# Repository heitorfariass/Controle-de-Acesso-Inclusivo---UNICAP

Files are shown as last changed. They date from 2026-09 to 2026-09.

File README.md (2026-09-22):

# ♿ Sistema Robótico de Destravamento com RFID — Acessibilidade UNICAP

<p align="center">
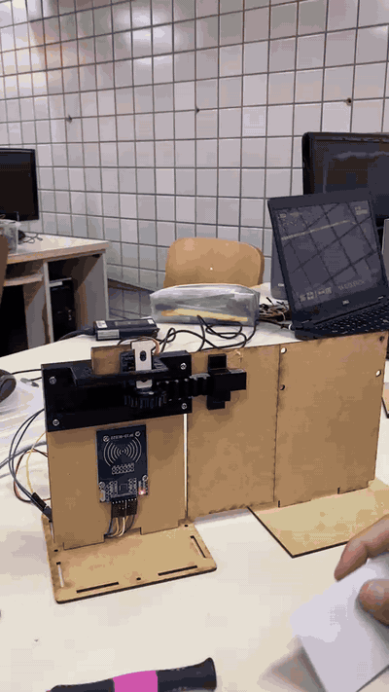
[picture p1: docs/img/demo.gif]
Sistema de destravamento RFID em funcionamento: o cartão é aproximado e a trava do portão é acionada pelo mecanismo impresso em 3D
  
</p>

> **Uma porta que abre sem pedir ajuda.** Projeto acadêmico da disciplina de Robótica Inclusiva (UNICAP) que devolve autonomia a estudantes com mobilidade reduzida: basta aproximar o cartão e a trava destrava sozinha.








➡️ **[Documentação técnica completa (PDF)](docs/documentacao-tecnica.pdf)** • **[Peças para impressão 3D](hardware/stl/)** • **[Vídeo completo do protótipo](docs/img/demo.mp4)**

---

## 🎯 O problema

Na universidade, o acesso de estudantes cadeirantes às instalações depende de que **alguém abra manualmente a porta de acessibilidade**. Na prática, isso significa esperar, chamar terceiros e, muitas vezes, passar por situações constrangedoras para realizar algo tão simples quanto entrar em uma sala.

## 💡 A solução

Um **sistema de destravamento com RFID** controlado por Arduino: ao aproximar um cartão autorizado, um servo motor aciona uma trava impressa em 3D e a porta se abre — sem depender de ninguém. O cadastro de novos usuários é feito pelo próprio dispositivo, com um **Cartão Mestre**, e tudo fica salvo na memória do Arduino, **100% offline**.

| Sem o projeto 😕 | Com o projeto 😃 |
| :--- | :--- |
| Esperar um terceiro abrir a porta | Aproximar o cartão e entrar |
| Dependência e constrangimento | Autonomia e independência |
| Nenhum registro de acesso | Base pronta para logs futuros |

---

## 🎬 Demonstração

> ⚡ O GIF do topo é gerado do vídeo real do protótipo — [assista ao vídeo completo, com áudio](docs/img/demo.mp4).

### 🛠️ Jornada de desenvolvimento

O projeto evoluiu por marcos claros — dos primeiros testes de leitura ao mecanismo funcional:

| 1️⃣ Primeiros testes do RFID | 2️⃣ Montagem mecânica v1 (MDF) |
| :---: | :---: |
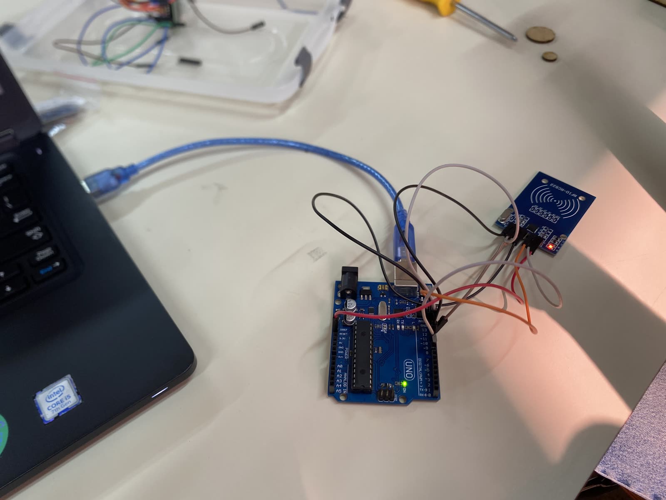
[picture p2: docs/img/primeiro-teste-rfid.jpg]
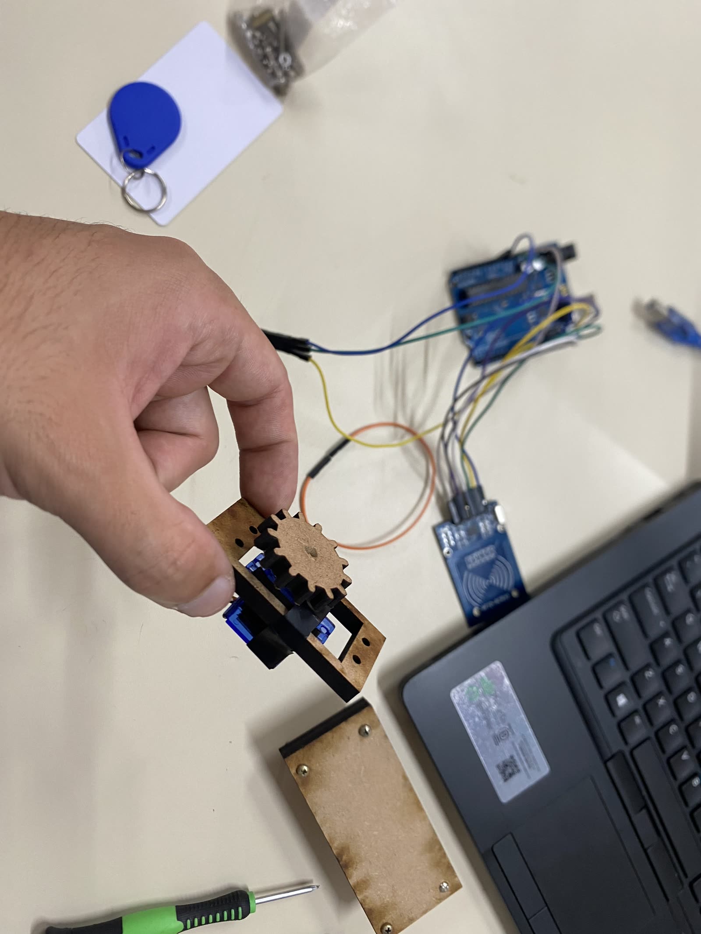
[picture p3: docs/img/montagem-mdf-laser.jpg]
|  |  |
| *Primeiro contato e leituras com o módulo RC522* | *Estrutura em MDF cortado a laser — substituída por peças impressas em 3D (ver [Desafios](#-desafios-e-soluções))* |

---

## ⚙️ Funcionalidades

- **🔓 Controle de acesso físico:** destravamento automatizado via leitura de tags RFID (13,56 MHz).
- **🔀 Acionamento em alternância (toggle):** a mesma leitura abre ou fecha a porta.
- **🗝️ Gestão via Master Card:** cadastro e remoção de usuários direto no dispositivo, sem plugar o Arduino no computador.
- **💾 Armazenamento não-volátil:** UIDs salvos na EEPROM nativa (até 10 cartões no código atual, expansível) — sobrevive a quedas de energia.
- **📴 100% offline:** sem internet, sem servidor, sem nuvem.

---

## 🧠 Arquitetura

O firmware é uma **máquina de estados** com três modos de operação, o que permite administrar usuários pelo próprio leitor:

```mermaid
stateDiagram-v2
    [*] --> NORMAL

    NORMAL --> ADMIN : Master Card
    NORMAL --> NORMAL : Tag autorizada → abre/fecha porta
    NORMAL --> NORMAL : Tag desconhecida → acesso negado

    ADMIN --> NORMAL : Master Card (encerra o modo)
    ADMIN --> NORMAL : Tag nova → cadastrada na EEPROM
    ADMIN --> AGUARDANDO_REMOCAO : Tag já cadastrada

    AGUARDANDO_REMOCAO --> NORMAL : Mesma tag → confirma remoção
    AGUARDANDO_REMOCAO --> NORMAL : Master Card → cancela
```

### Fluxo de sinais do sistema

```mermaid
flowchart LR
    A[Cartão RFID] -->|rádio 13,56 MHz| B[Leitor RC522]
    B -->|SPI| C[Arduino Uno<br/>máquina de estados + EEPROM]
    C -->|PWM| D[Servo 360°]
    D --> E[Mecanismo<br/>cremalheira e pinhão 3D]
    E --> F[Trava do portão]
    C <-.->|gravação/leitura| G[EEPROM<br/>até 10 UIDs]
```

---

## 🛠️ Hardware

### Lista de componentes (BOM)

| Componente | Especificação | Qtd. | Custo estimado* |
| :--- | :--- | :---: | :--- |
| Arduino Uno | R3 (ou compatível) | 1 | R$ 60–120 |
| Leitor RFID | RC522, 13,56 MHz | 1 | R$ 10–20 |
| Servo motor | SG90 modificado p/ rotação contínua (360°) | 1 | R$ 15–30 |
| Cartões/tags RFID | Kit com cartões e chaveiros | 1 kit | R$ 10–15 |
| Protoboard + jumpers | — | 1 kit | R$ 20–40 |
| Mecânica | MDF cortado a laser + peças impressas em 3D | 1 | R$ 30–60 |
| **Total** | | | **≈ R$ 150–300** |

> \* Valores aproximados em reais, com componentes nacionais/genéricos.

### 🔌 Esquema de ligação (pinagem)

| Componente | Pino do componente | Pino do Arduino |
| :--- | :--- | :--- |
| RFID RC522 | SDA (SS) | Digital 10 |
| RFID RC522 | SCK | Digital 13 |
| RFID RC522 | MOSI | Digital 11 |
| RFID RC522 | MISO | Digital 12 |
| RFID RC522 | IRQ | *Não conectado* |
| RFID RC522 | RST | Digital 9 |
| RFID RC522 | GND | GND |
| RFID RC522 | **3.3V** | 3.3V |
| Servo motor | Sinal (laranja/amarelo) | Digital 7 |
| Servo motor | VCC (vermelho) | 5V *(recomendado fonte externa)* |
| Servo motor | GND (marrom/preto) | GND |

> ⚠️ **Atenção:** o RC522 **não tolera 5V** no pino de alimentação — conecte-o **exclusivamente ao 3.3V**, sob risco de queimar o módulo.

---

## 🖨️ Mecânica

A trava é um mecanismo de **cremalheira e pinhão** impresso em 3D, acoplado ao servo de rotação contínua; a estrutura do portão é cortada a laser em MDF.

As **quatro peças** do mecanismo estão prontas para reimpressão em [`hardware/stl/`](hardware/stl/):

| Peça | Arquivo | Função |
| :--- | :--- | :--- |
| Pinhão (engrenagem) | [`gear.stl`](hardware/stl/gear.stl) | Acoplado ao servo, converte rotação em movimento linear |
| Cremalheira | [`gear_rack.stl`](hardware/stl/gear_rack.stl) | Trava linear acionada pelo pinhão |
| Suporte do motor | [`motor_holder.stl`](hardware/stl/motor_holder.stl) | Fixa o servo à estrutura |
| Suporte da cremalheira | [`rack_holder.stl`](hardware/stl/rack_holder.stl) | Guiamento e fixação da cremalheira |

- **Parâmetros de impressão:** material, infill e suportes documentados em [`hardware/stl/README.md`](hardware/stl/README.md)

---

## 🚀 Como instalar e usar

### 1. Dependências

Instale as bibliotecas no IDE do Arduino (Sketch → Incluir Biblioteca → Gerenciar Bibliotecas):

- [`MFRC522`](https://github.com/miguelbalboa/rfid) (GithubCommunity)
- `Servo` (nativa)
- `EEPROM` (nativa)
- `SPI` (nativa)

### 2. Configure o Cartão Mestre

Abra `firmware/destravamento_rfid/destravamento_rfid.ino` e informe o UID do cartão administrador na variável `masterID`:

```cpp
String masterID = "63:13:ED:1B";
```

> 💡 Para descobrir o UID de um cartão, rode um sketch de leitura RFID (ou o próprio firmware) e veja o UID no Monitor Serial (9600 baud).

### 3. Faça o upload

Conecte o Arduino Uno via USB, selecione a placa e a porta corretas e clique em **Upload**. Abra o **Monitor Serial (9600)** para acompanhar tudo em tempo real.

### 4. Modo de operação

**No dia a dia (Modo NORMAL):**
| Ação | Resultado |
| :--- | :--- |
| Aproximar cartão **cadastrado** | Porta destrava/trava (alternância) |
| Aproximar cartão **desconhecido** | Acesso negado |

**Administrando usuários:**
1. 🗝️ Aproxime o **Master Card** → o sistema entra em **MODO ADMIN**.
2. ➕ Aproxime uma **tag nova** → ela é cadastrada e salva na EEPROM, e o sistema volta ao modo normal.
3. ➖ Aproxime uma **tag já cadastrada** (em modo admin) → o sistema pede confirmação: aproxime **a mesma tag novamente** para removê-la, ou o **Master Card** para cancelar.
4. 🗝️ Aproxime o **Master Card** de novo → encerra o modo admin.

Tudo é confirmado no Monitor Serial — nenhuma ferramenta além do leitor é necessária.

---

## 🧗 Desafios e soluções

| Desafio | Como resolvemos |
| :--- | :--- |
| A estrutura em MDF cortado a laser não funcionou como esperado | Redesenho completo do mecanismo para **impressão 3D** (cremalheira, pinhão e suportes), com tolerâncias e resistência adequadas — [peças disponíveis no repo](hardware/stl/) |
| O RC522 queima com 5V | Alimentação dedicada ao 3.3V do Arduino e aviso documentado na pinagem |
| Servo de rotação contínua não tem posição fixa | Calibração do neutro em 90° e pulsos de 80°/100° com temporização de 1 s para abrir/fechar de forma controlada |
| Cadastro não poderia depender de computador | Máquina de estados administrativa acionada pelo próprio Master Card, com confirmação em duas leituras para remoção |
| Cadastros não podiam se perder ao desligar | Persistência dos UIDs na EEPROM: contador no endereço 0 + IDs em blocos de 12 bytes |

---

## 🗺️ Roadmap

Ideias para próximas versões — contribuições são bem-vindas:

- [ ] Feedback sonoro e visual (buzzer + LED verde/vermelho)
- [ ] Display OLED com status do sistema
- [ ] ESP32 + registro de acessos com data/hora (RTC)
- [ ] Interface web para gestão de cartões
- [ ] Alimentação por bateria/power bank
- [ ] Aumento da capacidade de cartões (EEPROM externa ou I²C)

---

## 👥 Equipe

| Nome | GitHub | LinkedIn |
| :--- | :--- | :--- |
| Heitor Farias Santos | [@heitorfariass](https://github.com/heitorfariass) | www.linkedin.com/in/heitorfariassantos/ |
| João da Fonte | [@joaodafontequeiroz](https://github.com/joaodafontequeiroz) | www.linkedin.com/in/joao-da-fonte-queiroz-280822363 |
| Nina Lira | [@ninalira](https://github.com/ninalira) | www.linkedin.com/in/nina-lira-b29961325/ |
| Marcelo Caldas | [@Marcelo07092005](https://github.com/Marcelo07092005) | www.linkedin.com/in/marcelo-caldas-de-ara%C3%BAjo-filho-4aa669394/ |

## 🙏 Agradecimentos

À disciplina de **Robótica Inclusiva** da [UNICAP — Universidade Católica de Pernambuco](https://www.unicap.br/) e aos professores *Wilmer Cordoba e Emmanuel Barreto*, pela orientação e pelo incentivo a projetos com impacto social real.

---

## 📄 Licença

Este projeto está sob a licença [MIT](LICENSE) — sinta-se livre para estudar, reproduzir e adaptar.

<p align="right"><sub>Feito com 💜 por estudantes que acreditam que tecnologia boa é tecnologia que inclui.</sub></p>

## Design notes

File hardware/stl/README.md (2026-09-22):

# 🖨️ Mecânica — Peças Impressas em 3D

Mecanismo de trava **cremalheira e pinhão** do Sistema Robótico de Destravamento com RFID (UNICAP).

> 📖 Contexto: a primeira versão mecânica, em MDF cortado a laser, não funcionou como esperado — o mecanismo foi redesenhado para impressão 3D. Os arquivos abaixo são os **utilizados na versão final do protótipo**.

## Peças

| Arquivo | Peça | Função |
| :--- | :--- | :--- |
| [`gear.stl`](gear.stl) | Pinhão (engrenagem) | Acoplado ao servo de rotação contínua; converte rotação em movimento linear |
| [`gear_rack.stl`](gear_rack.stl) | Cremalheira | Trava linear acionada pelo pinhão |
| [`motor_holder.stl`](motor_holder.stl) | Suporte do motor | Fixa o servo à estrutura do portão |
| [`rack_holder.stl`](rack_holder.stl) | Suporte da cremalheira | Guiamento e fixação da cremalheira |

## Parâmetros de impressão utilizados

> ✏️ **A ajustar pela equipe** — confirme os valores da impressão real (a tabela já é referenciada no README).

| Parâmetro | Valor |
| :--- | :--- |
| Material | PLA |
| Altura de camada | 0,2 mm |
| Preenchimento (infill) | — % |
| Suportes | Sim / Não |
| Bordas (brim) | — |
| Tempo aproximado de impressão | — |

## Dica

Se as peças foram modeladas em Tinkercad, Fusion 360 ou similar, considere subir também
o arquivo de origem (`.f3d`, `.step`, link do projeto) para facilitar a reprodução por
outros estudantes.

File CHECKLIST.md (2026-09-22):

# ✅ Checklist — Transformar o repositório em peça de portfólio

## 1. Materiais enviados ✅
- [x] 🎥 Vídeo → convertido em `docs/img/demo.gif` (otimizado) + `docs/img/demo.mp4` (completo, com áudio)
- [x] 📸 Foto dos primeiros testes do RFID → `docs/img/primeiro-teste-rfid.jpg`
- [x] 📸 Foto da montagem em MDF a laser → `docs/img/montagem-mdf-laser.jpg` (usada na jornada de desenvolvimento)
- [x] 🖨️ 4 arquivos STL → `hardware/stl/` (já linkados na seção Mecânica)
- [x] 📄 Documentação (PDF) → `docs/documentacao-tecnica.pdf` (linkada no topo do README)

## 2. Arquivos que ainda faltam
- [ ] 📸 **Foto do protótipo completo e montado** → hoje o `docs/img/social-preview.jpg` (frame extraído do vídeo) serve de capa provisória para o *Social Preview*; uma foto boa do protótipo montado substituiria com vantagem
- [ ] ✏️ Parâmetros reais da impressão 3D → editar `hardware/stl/README.md`
- [ ] 🔗 LinkedIn/GitHub da equipe → editar seção Equipe do README
- [ ] 👨‍🏫 Nome do professor/disciplina → seção Agradecimentos do README

## 2. Ações de 5 minutos no GitHub (Settings do repositório)
- [ ] **Description:** `Sistema de destravamento de porta com Arduino + RFID para autonomia de estudantes com mobilidade reduzida — Robótica Inclusiva / UNICAP`
- [ ] **Topics:** `arduino` `rfid` `accessibility` `inclusao` `robotics` `arduino-uno` `rc522` `servo` `eeprom`
- [ ] **Social Preview** (Settings → General): subir `docs/img/hero.png`
- [ ] **Fixar o repositório** no seu perfil (customize your pins)
- [ ] Conferir se o botão **"Cite this repository"** apareceu (gerado pelo `CITATION.cff`)

## 3. Toque final (opcional)
- [ ] QR code do repositório colado no portão de MDF — no dia da apresentação, banca e público escaneiam e caem direto no projeto 📸
- [ ] Gravar 20–30 s de vídeo vertical para LinkedIn, com link do repo na descrição
- [ ] Post no LinkedIn marcando a equipe e a universidade

## 4. Depois que as imagens finais entrarem
- [ ] Substituir o arquivo de origem das fotos se houver versões melhores do protótipo montado
- [ ] Última leitura do README como "pessoa de fora" — a primeira dobra precisa vender o projeto sozinha

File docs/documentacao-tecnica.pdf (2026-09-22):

# Catraca de Acessibilidade Inteligente

Universidade Católica de Pernambuco — UNICAP

### 1. Problemática

Na Universidade Católica de Pernambuco (UNICAP), o sistema de controle de acesso por catracas convencionais já atende o fluxo diário e opera de forma eficiente para a maioria do público. No entanto, a rota de acesso específica para pessoas com deficiência apresenta um desafio direto à inclusão, impactando especificamente os alunos cadeirantes. Enquanto o público geral valida seu acesso rapidamente nas catracas normais, o portão de vidro dedicado à acessibilidade opera de forma totalmente manual.

Na prática, isso retira a autonomia do cadeirante. Para entrar ou sair das dependências da universidade por essa rota exclusiva, esse usuário não consegue simplesmente validar seu acesso de forma independente. Atualmente, o cadeirante é obrigado a aguardar que um segurança ou funcionário perceba sua presença, faça a liberação no sistema e empurre a porta fisicamente. Essa dependência de terceiros em um acesso que deveria ser facilitado gera esperas desnecessárias, constrangimentos e vai na contramão do conceito de acessibilidade universal, que defende o direito de ir e vir com dignidade e total independência dentro do ambiente acadêmico.

### 2. Motivação

A motivação central deste projeto é transformar o acesso na UNICAP, tornando-o genuinamente inclusivo, autônomo e seguro. O objetivo é demonstrar a viabilidade prática de automatizar o portão de acessibilidade existente por meio da integração de tecnologias de hardware livre e baixo custo.

A solução final desenvolvida foca na liberação automatizada e confiável por radiofrequência (RFID) aliada a um atuador mecânico direto. Ao aproximar um cartão cadastrado, o usuário destranca a porta automaticamente e, para garantir total segurança e flexibilidade no tempo de travessia, o fechamento não ocorre por temporizador: a trava só volta a fechar quando um cartão autorizado é aproximado novamente do leitor RFID. Essa abordagem robusta redefine o fluxo de entrada, garantindo que o campus respeite o tempo necessário para cada indivíduo, eliminando completamente o risco de fechamentos prematuros ou acidentes durante a passagem.

### 3. Funcionamento Lógico do Sistema

O comportamento do protótipo foi projetado como uma Máquina de Estados Finita, operando em três modos principais de forma contínua:

Modo Normal (Espera)
O sistema permanece aguardando a aproximação de uma tag RFID. O servo motor é mantido no sinal neutro (90), garantindo que a porta permaneça parada e na posição atual.

Modo Admin (Cadastro e Remoção Segura)

Ao aproximar o "Cartão Mestre" (administrador), o Arduino entra em modo de gerenciamento. Neste modo:

- Para Adicionar: O próximo cartão desconhecido aproximado terá seu ID gravado permanentemente na memória interna (EEPROM) do microcontrolador, limitado a 10 vagas.
- Para Remover: Se um cartão já cadastrado for aproximado, o sistema entra em um subestado de "Aguardando Remoção", exigindo que o mesmo cartão seja aproximado uma segunda vez para confirmar a exclusão, evitando exclusões acidentais. Após a ação, o sistema retorna automaticamente ao modo normal.

Modo Operação (Acesso Autorizado e Fechamento Manual por RFID)
Quando um cartão válido é detectado na lista branca, o sistema altera o estado da trava. Se o portão estiver trancado, o Arduino envia um sinal (60) ao servo motor contínuo por 1,5 segundos para recolher o trinco e abrir o portão, permanecendo aberto por tempo indeterminado para que o cadeirante passe sem pressa. O portão só executa o movimento reverso de fechamento quando um cartão cadastrado for passado novamente no leitor RFID, momento em que o motor recebe o comando inverso (120) por 1,5 segundos para empurrar o trinco e trancar a porta, retornando em seguida ao estado de repouso (90).

### 4. Lista de Componentes do Protótipo

Categoria | Componente | Função
Microcontrolador | Arduino Uno R3 | Responsável pelo processamento lógico, controle de estados e armazenamento na memória EEPROM.
Módulo RFID | Leitor MFRC522 (13,56 MHz) | Responsável pela leitura, validação e comando de abertura/fechamento por aproximação de cartões.
Atuador Mecânico | Servo Motor de Rotação Contínua (360º) | Substitui o tracionamento passo a passo complexo por um acionamento direto via PWM, garantindo torque para abrir e fechar a trava da porta de vidro conforme os comandos do RFID.
Estrutura do Terminal | Gabinete em MDF ou Acrílico de 3mm cortado a laser | Garante a proteção mecânica do Arduino e do leitor RFID nas instalações.
Alimentação e Conexões | Fonte Externa de 5V e jumpers diversos | Fonte Externa de 5V (para não sobrecarregar o Arduino com o motor) e jumpers diversos para ligação em protoboard.

### 5. Esquema de Ligação Pino a Pino (Pinagem)

Para a montagem e replicação do circuito em bancada, as conexões elétricas devem seguir rigorosamente a distribuição simplificada abaixo:

Módulo RFID (MFRC522)

Nota crítica: Ligar obrigatoriamente no pino de 3.3V do Arduino.

Pino do Módulo | Conexão no Arduino
3.3V | 3.3V do Arduino
RST | Pino Digital 9
GND | GND do Arduino
MISO | Pino Digital 12
MOSI | Pino Digital 11
SCK | Pino Digital 13
SDA (SS) | Pino Digital 10

Atuador: Servo Motor 360º

Pino do Servo | Conexão no Arduino / Circuito
VCC (Fio Vermelho) | 5V
GND (Fio Marrom/Preto) | GND comum do circuito
Sinal (Fio Laranja/Amarelo) | Pino Digital 7

Diagrama de Ligação (Esquema Visual)

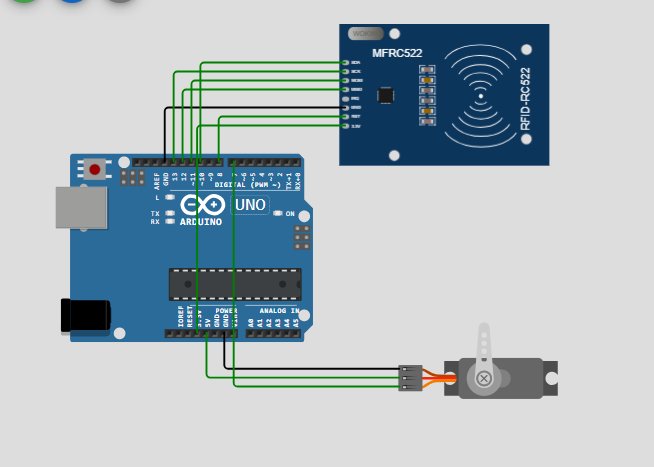
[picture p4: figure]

Figura 1 — Representação do circuito: Arduino Uno R3, módulo leitor RFID MFRC522 e servo motor de rotação contínua, conforme a pinagem descrita acima.

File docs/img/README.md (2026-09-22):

# 📁 Imagens e mídia do projeto

Conteúdo atual desta pasta:

| Arquivo | O que é |
| :--- | :--- |
| `demo.gif` | GIF otimizado (400 px, 8 fps) do vídeo real do protótipo — exibido no topo do README |
| `demo.mp4` | Vídeo completo original (com áudio) — reproduzido nativamente pelo GitHub |
| `primeiro-teste-rfid.jpg` | Primeiro contato e testes com o leitor RC522 |
| `montagem-mdf-laser.jpg` | Montagem da estrutura v1 em MDF cortado a laser (depois substituída por peças 3D) |

## O que ainda pode entrar aqui

- **Foto do protótipo completo montado** (horizontal, bem iluminado) — seria a capa ideal
  para o *Social Preview* do GitHub (Settings → General → Social preview) e pode substituir
  ou acompanhar o GIF no topo do README.
- Fotos de detalhe da eletrônica e do mecanismo de trava instalado, para enriquecer a galeria.

> O GIF foi gerado a partir do vídeo com ffmpeg (paleta otimizada). Se o vídeo for regravado,
> regenere com: `ffmpeg -i video.mp4 -vf "fps=8,scale=400:-1,palettegen" p.png` e depois
> `ffmpeg -i video.mp4 -i p.png -lavfi "fps=8,scale=400:-1[x];[x][1:v]paletteuse=dither=bayer:bayer_scale=5" -loop 0 demo.gif`.

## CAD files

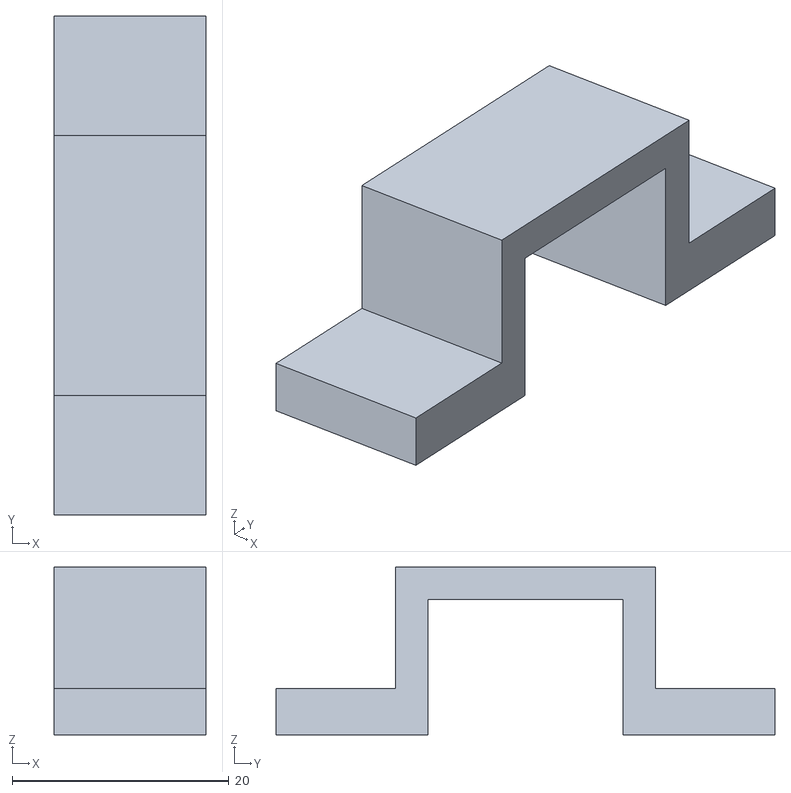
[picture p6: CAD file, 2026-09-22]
hardware/stl/rack_holder.stl
14.0 x 46.0 x 15.5

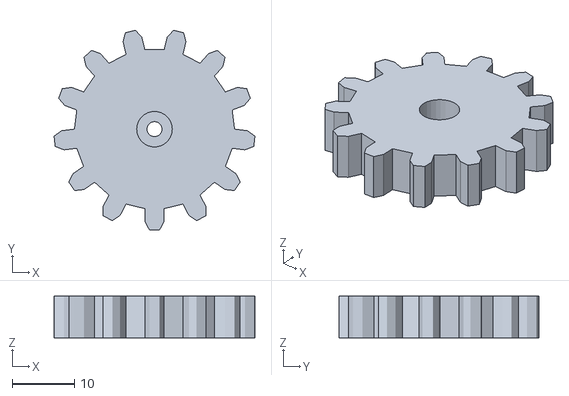
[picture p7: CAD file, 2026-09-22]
hardware/stl/gear.stl
32.3 x 32.1 x 6.69

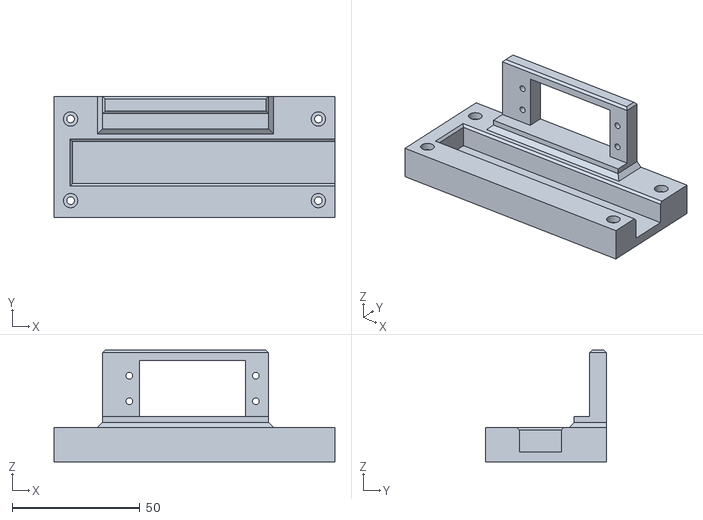
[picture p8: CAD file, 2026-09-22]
hardware/stl/motor_holder.stl
110.0 x 47.5 x 43.7

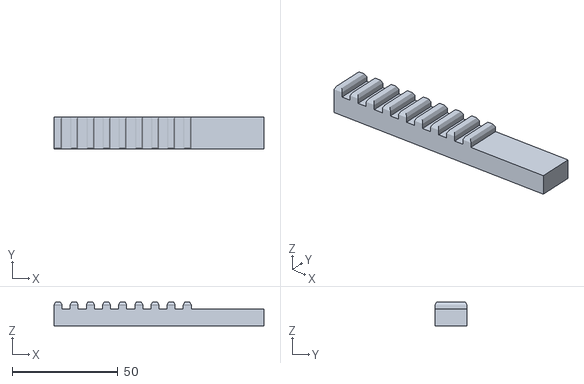
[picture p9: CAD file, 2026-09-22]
hardware/stl/gear_rack.stl
99.3 x 15.0 x 11.3

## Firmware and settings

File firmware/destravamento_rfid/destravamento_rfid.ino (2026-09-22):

#include <SPI.h>
#include <MFRC522.h>
#include <EEPROM.h>
#include <Servo.h> 

#define SS_PIN 10
#define RST_PIN 9

MFRC522 rfid(SS_PIN, RST_PIN);

Servo meuServo;
#define PINO_SERVO 7

String masterID = "63:13:ED:1B"; 
String whitelist[10];            
int cartoesCadastrados = 0;

enum EstadoSistema { NORMAL, ADMIN, AGUARDANDO_REMOCAO };
EstadoSistema estadoAtual = NORMAL;
String tagPendenteRemocao = ""; 

const int TAMANHO_ID = 12;

bool portaAberta = false;

void carregarEEPROM();
void salvarNaEEPROM(int indice, String id);
void atualizarContadorEEPROM();
int buscarTag(String id);
void removerTag(String id);
void acionarPorta();

void setup() {
  Serial.begin(9600);
  SPI.begin();
  rfid.PCD_Init();

  meuServo.attach(PINO_SERVO);
  meuServo.write(90); 

  carregarEEPROM();

  Serial.println("--- SISTEMA DE ACESSO UNICAP ---");
  Serial.print("Tags atualmente cadastradas na memoria: ");
  Serial.println(cartoesCadastrados);
  Serial.println("Aproxime o Master Card para gerenciar o sistema.");
}

void loop() {
  if (!rfid.PICC_IsNewCardPresent()) return;
  if (!rfid.PICC_ReadCardSerial()) return;

  String idLido = "";
  for (byte i = 0; i < rfid.uid.size; i++) {
    idLido += (rfid.uid.uidByte[i] < 0x10 ? "0" : "");
    idLido += String(rfid.uid.uidByte[i], HEX);
    if (i < rfid.uid.size - 1) idLido += ":"; 
  }
  idLido.toUpperCase();

  Serial.print("\nTag detectada: [" + idLido + "]");

  if (idLido == masterID) {
    if (estadoAtual == AGUARDANDO_REMOCAO) {
      Serial.println("\n>>> REMOCAO CANCELADA. Retornando ao Modo Normal.");
      estadoAtual = NORMAL;
      tagPendenteRemocao = "";
    } else if (estadoAtual == NORMAL) {
      estadoAtual = ADMIN;
      Serial.println("\n>>> MODO ADMIN ATIVADO. Aproxime tag para cadastrar ou remover.");
    } else if (estadoAtual == ADMIN) {
      estadoAtual = NORMAL;
      Serial.println("\n>>> MODO ADMIN DESATIVADO.");
    }
  } 
  else if (estadoAtual == ADMIN) {
    int indiceEncontrado = buscarTag(idLido);
    
    if (indiceEncontrado >= 0) {
      estadoAtual = AGUARDANDO_REMOCAO;
      tagPendenteRemocao = idLido;
      Serial.println("\nAVISO: Este cartao ja esta cadastrado. Deseja remove-lo?");
      Serial.println("-> Aproxime a MESMA tag novamente para CONFIRMAR a remocao.");
      Serial.println("-> Aproxime o Master Card para CANCELAR a operacao.");
    } else {
      if (cartoesCadastrados < 10) {
        whitelist[cartoesCadastrados] = idLido;
        salvarNaEEPROM(cartoesCadastrados, idLido);
        cartoesCadastrados++;
        atualizarContadorEEPROM();
        Serial.println("\nSUCESSO: Cartao cadastrado com seguranca offline!");
      } else {
        Serial.println("\nERRO: Lista cheia!");
      }
      estadoAtual = NORMAL; 
    }
  } 
  else if (estadoAtual == AGUARDANDO_REMOCAO) {
    if (idLido == tagPendenteRemocao) {
      removerTag(idLido);
      Serial.println("\nSUCESSO: Tag removida definitivamente do sistema!");
      estadoAtual = NORMAL;
      tagPendenteRemocao = "";
    } else {
      Serial.println("\nERRO: Tag diferente. Aproxime a tag correta para confirmar remocao ou Master Card para cancelar.");
    }
  }
  else {
    if (buscarTag(idLido) >= 0) {
      acionarPorta();
    } else {
      Serial.println("\nACESSO NEGADO.");
    }
  }

  rfid.PICC_HaltA();
  rfid.PCD_StopCrypto1();
}

int buscarTag(String id) {
  for (int i = 0; i < cartoesCadastrados; i++) {
    if (whitelist[i] == id) return i;
  }
  return -1;
}

void removerTag(String id) {
  int indice = buscarTag(id);
  if (indice == -1) return; 

  for (int i = indice; i < cartoesCadastrados - 1; i++) {
    whitelist[i] = whitelist[i + 1];
  }
  
  whitelist[cartoesCadastrados - 1] = ""; 
  cartoesCadastrados--;
  atualizarContadorEEPROM();

  for (int i = 0; i < cartoesCadastrados; i++) {
    salvarNaEEPROM(i, whitelist[i]);
  }
}

void carregarEEPROM() {
  cartoesCadastrados = EEPROM.read(0);

  if(cartoesCadastrados > 10 || cartoesCadastrados < 0) {
    cartoesCadastrados = 0;
    EEPROM.write(0, 0);
  }

  for (int i = 0; i < cartoesCadastrados; i++) {
    int enderecoBase = 1 + (i * TAMANHO_ID);
    char buffer[TAMANHO_ID];

    for(int j = 0; j < TAMANHO_ID; j++) {
      buffer[j] = EEPROM.read(enderecoBase + j);
    }
    whitelist[i] = String(buffer);
  }
}

void salvarNaEEPROM(int indice, String id) {
  int enderecoBase = 1 + (indice * TAMANHO_ID);

  char buffer[TAMANHO_ID];
  id.toCharArray(buffer, TAMANHO_ID);

  for(int j = 0; j < TAMANHO_ID; j++) {
    EEPROM.write(enderecoBase + j, buffer[j]);
  }
}

void atualizarContadorEEPROM() {
  EEPROM.write(0, cartoesCadastrados);
}

void acionarPorta() {
  if (!portaAberta) {
    Serial.println("\nABRINDO PORTA...");
    meuServo.write(80); 
    delay(1000); 
    meuServo.write(90); 
    Serial.println("PORTA ABERTA.");
    portaAberta = true;
  } else {
    Serial.println("\nFECHANDO PORTA...");
    meuServo.write(100); 
    delay(1000); 
    meuServo.write(90); 
    Serial.println("PORTA TRANCADA.");
    portaAberta = false;
  }
}

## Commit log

2026-06-18 Revise README with project details and installation guide
    Updated project title and added detailed project description, team members, main features, hardware components, wiring diagram, and installation instructions.
2026-09-22 atualização completa do projeto
    [gear.stl, gear_rack.stl, motor_holder.stl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]
